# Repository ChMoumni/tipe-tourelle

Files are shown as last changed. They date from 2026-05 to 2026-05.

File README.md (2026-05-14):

# TIPE – Tourelle de visée motorisée

<p align="center">
  Système complet
</p>

Conception et réalisation d'une tourelle motorisée pilotée par joystick, avec suivi automatique d'objet par caméra Pixy2 et système de tir électromagnétique (coilgun).  
Projet mené dans le cadre de mon TIPE (2025-2026).

## 🎯 Objectif du projet

Développer un système de visée motorisé capable de :
- Être piloté manuellement via un joystick
- Suivre automatiquement un objet coloré en temps réel
- Déclencher un tir électromagnétique sur cible
- Servir de plateforme d'étude pour l'asservissement et la cinématique

## 🛠️ Technologies utilisées

- **Microcontrôleur** : Arduino Uno
- **Langage** : C++ embarqué
- **Capteur** : Pixy2 CMUcam (reconnaissance couleur)
- **Actionneurs** : 2 servomoteurs FS5323M
- **Entrée** : Joystick analogique 2 axes
- **Simulation** : Wokwi
- **CAO** : FreeCAD & Autodesk Fusion 360

## 🎮 Fonctionnalités

### Mode Manuel
- Pilotage horizontal/vertical par joystick
- Zone morte configurable
- Vitesse progressive

### Mode Automatique
- Détection d'objets colorés
- Asservissement PD (Kp = 0,15, Kd = 0,05)
- Commutation manuel/auto par série

### Commandes série
- `a` : Mode automatique
- `m` : Mode manuel  
- `c` : Centrer la tourelle

## 🔫 Système de tir (Coilgun)

La tourelle intègre un canon électromagnétique (coilgun) en tête de système.

### Principe de fonctionnement
- Un banc de condensateurs (30 mF, 60 V) stocke l'énergie
- La décharge dans une bobine crée un champ magnétique puissant
- Une bille en acier (Ø 5 mm) est propulsée par effet magnétique

### Circuit électrique

| Composant | Valeur | Rôle |
|---|---|---|
| Condensateur | 30 mF (3 × 10 000 μF / 63 V) | Stockage d'énergie |
| Bobine | L = 1,4 mH, rL = 3 Ω | Inducteur |
| Résistance série | 0,1 Ω | Limitation du courant |
| Résistance de charge | 100 Ω | Charge du condensateur |
| MOSFET | IRFB4227 | Interrupteur de puissance |
| Diode | 1N5408 | Protection flyback |
| Résistance de grille | 470 Ω | Pilotage MOSFET |

### Performances actuelles
- Énergie stockée : **54 J**
- Énergie transmise au projectile : ≈ **0,5 J** (rendement ≈ 1%)
- Portée : plusieurs mètres

### Améliorations envisagées
- [ ] Dimensionnement optimal de la bobine (calculs en cours)
- [ ] Remplacer le MOSFET par un IGBT (IGW60T120) pour supporter des courants plus élevés
- [ ] Commande du tir depuis l'Arduino (automatisation)
- [ ] Réduction de la résistance interne de la bobine pour améliorer le rendement

> Voir section 7 du rapport pour les détails de conception et les essais.

## 🔗 Simulation du mode manuel (Wokwi)

[→ Simuler la commande joystick → servomoteurs](https://wokwi.com/projects/456061970656974849)

*Version préliminaire ayant servi de base au mode manuel actuel (sans zone morte ni gestion de vitesse). Le code final de la tourelle complète est disponible dans [`code/tipe_tourelle_visee.ino`](code/tipe_tourelle_visee.ino).*

## 🔧 Installation

1. Cloner le dépôt
2. Câbler selon schéma (servos pins 9/10, joystick A0/A1)
3. Téléverser le code Arduino
4. Ouvrir le moniteur série (115200 bauds)

## 📊 Résultats

<p align="center">
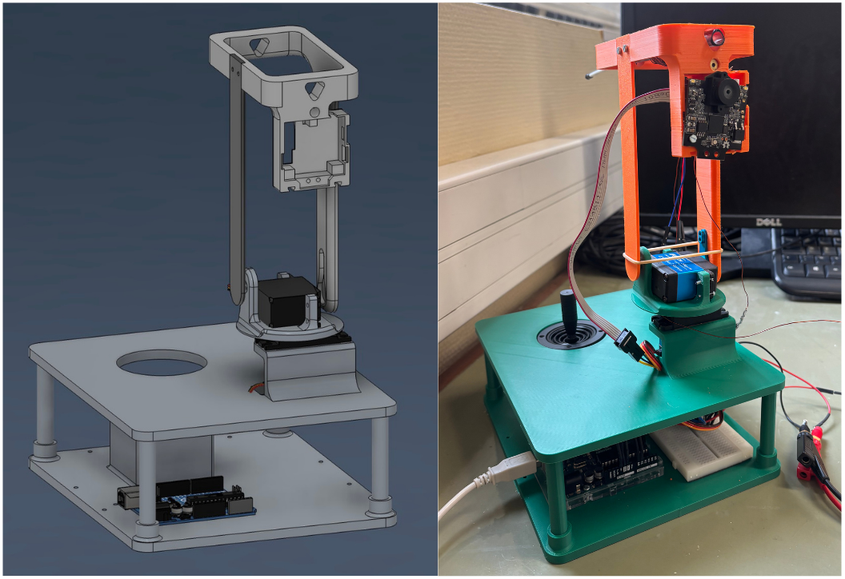
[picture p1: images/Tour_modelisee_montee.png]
Comparaison CAO / Réel
  
</p>

## 🧩 État d'avancement

### Mécanique
- [x] Modélisation 3D complète (6 pièces) [`cad/`](cad/) (visualisables directement sur GitHub)
- [x] Impression 3D
- [x] Assemblage final

### Électronique & Code
- [x] Simulation Wokwi (version préliminaire)
- [x] Câblage et tests
- [x] Code fonctionnel (manuel + auto)
- [x] Circuit coilgun opérationnel

### Système de tir
- [x] Banc de condensateurs 30 mF / 60 V
- [x] Bobine artisanale fonctionnelle
- [ ] Dimensionnement optimal de la bobine (calculs en cours)
- [ ] Amélioration du rendement énergétique

### Documentation
- [x] README
- [x] Description des pièces
- [ ] Rapport final (en cours - rédaction LaTeX)
- [ ] Schéma cinématique (graphe des liaisons)

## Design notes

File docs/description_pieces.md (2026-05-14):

# Description des pièces mécaniques

Ce document décrit le rôle de chaque pièce modélisée sur FreeCAD et Fusion 360.  
Une version définitive (schéma cinématique, graphe de liaisons) sera rédigée dans le rapport final.

**📁 Les fichiers CAO (`.stl` et `.step`) sont disponibles dans le dossier [`../cad/`](../cad/) et visualisables directement sur GitHub.**

---

## Vue d'ensemble des 6 pièces

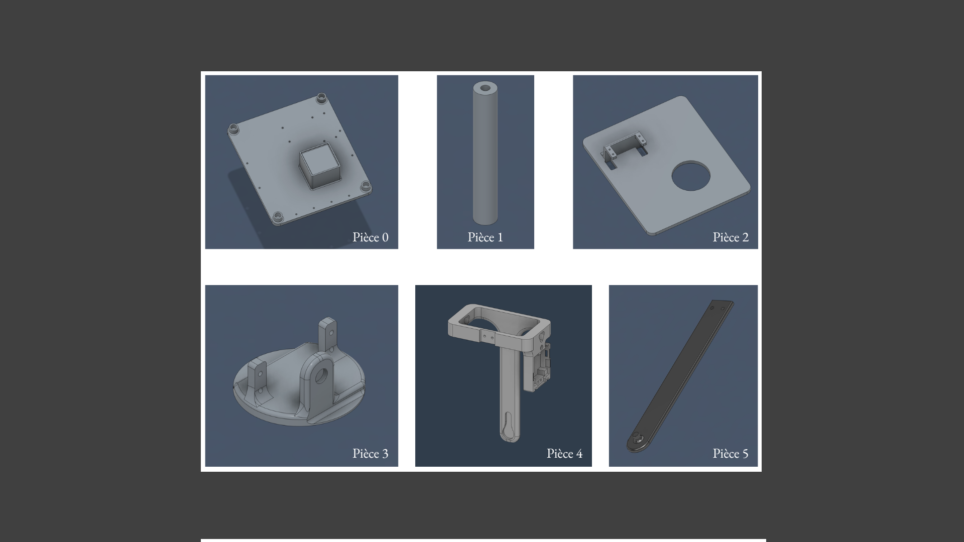
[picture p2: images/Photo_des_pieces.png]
Ensemble des 6 pièces


---

## Détail des pièces

| Pièce | Nom | Vue | Rôle |
|---|-----|-----|---|
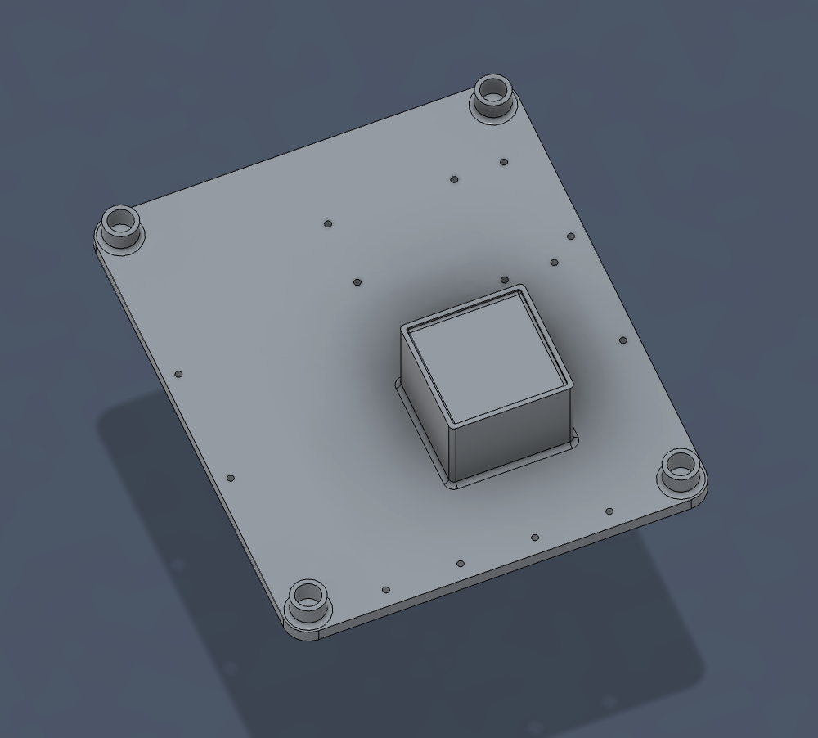
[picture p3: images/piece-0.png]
| **0** | Bâti (base fixe) |  | Base fixe de la tourelle. Accueille le breadboard, Arduino et joystick. Quatre logements cylindriques reçoivent les colonnes. |
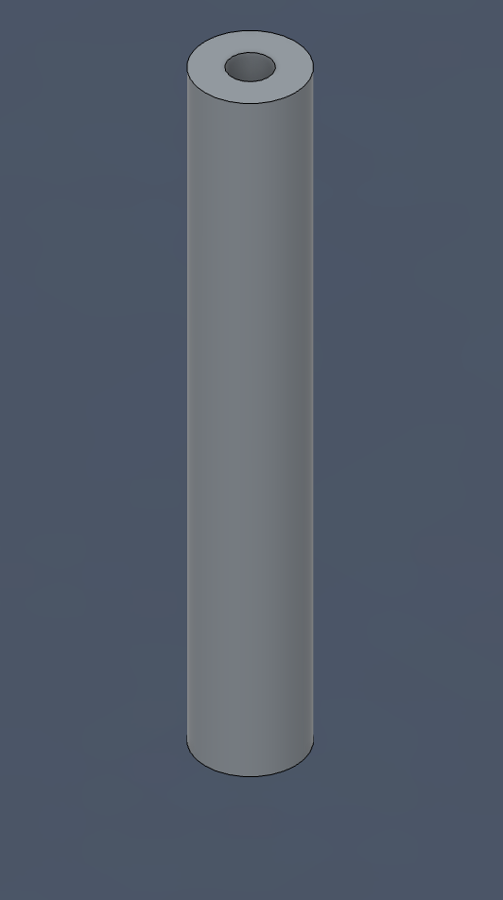
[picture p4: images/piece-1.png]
| **1** | Colonne (×4) |  | Colonne cylindrique creuse imprimée en 4 exemplaires. Sert de support entre la pièce 0 et la pièce 2. |
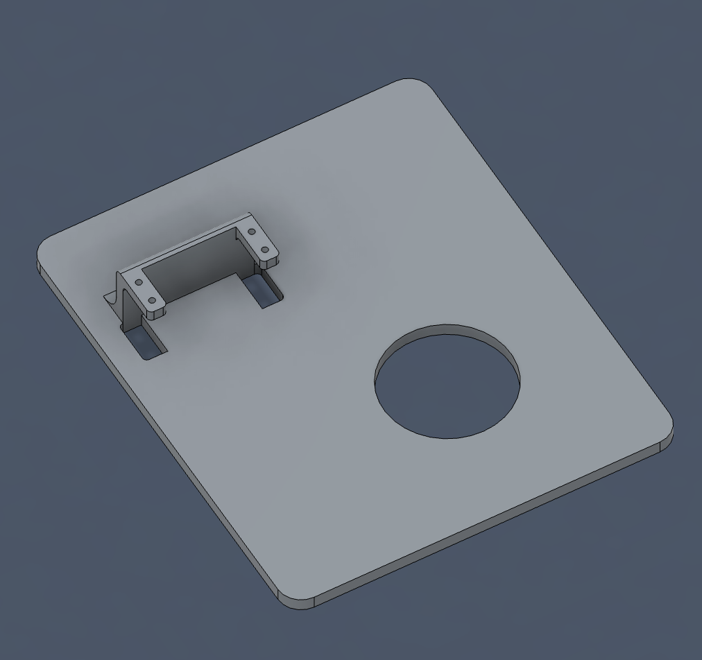
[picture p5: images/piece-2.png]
| **2** | Plateau intermédiaire |  | Porte le servomoteur horizontal. S'emboîte sur les colonnes. Protège les composants électroniques. |
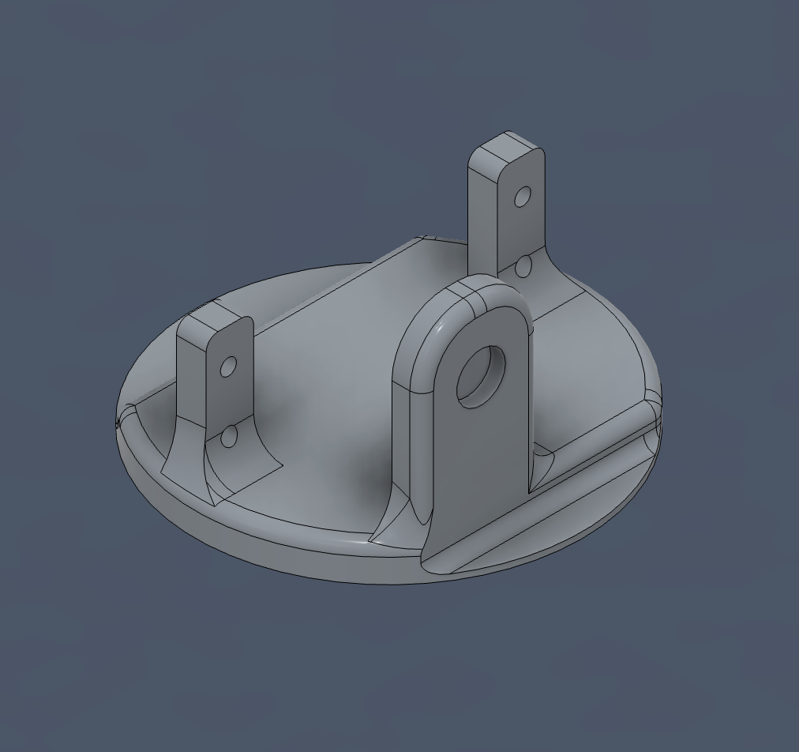
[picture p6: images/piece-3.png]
| **3** | Bras tournant |  | Encastré sur l'arbre du servo horizontal. Porte le servomoteur vertical. Logement pour roulement à billes. |
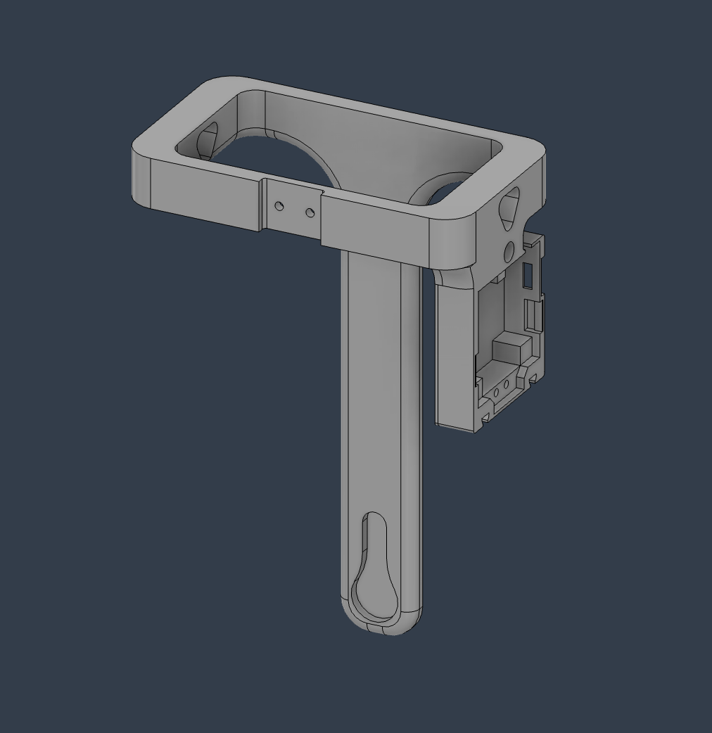
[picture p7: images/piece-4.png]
| **4** | Tête |  | Porte la caméra Pixy2, le laser et le **coilgun** (canon électromagnétique). Fixée sur le servo vertical. |
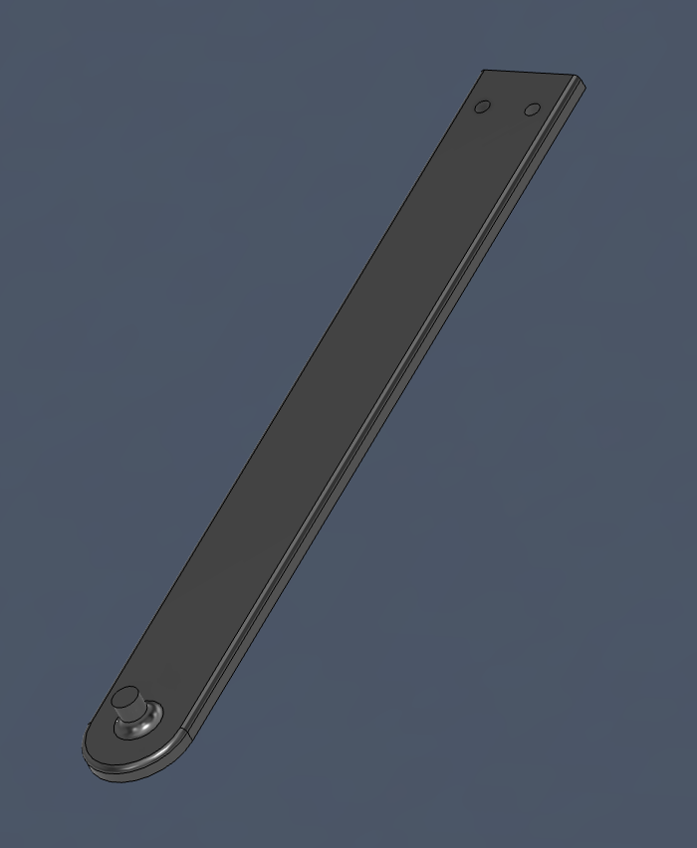
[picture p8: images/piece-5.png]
| **5** | Jonction |  | Vissée sur la pièce 4. Son cylindre se loge dans le roulement de la pièce 3, réalisant la liaison pivot. |

---

## Récapitulatif

| Pièce | Nom | Qté | Mouvement | Actionneur |
|---|-----|-----|---|---|
| 0 | Bâti | 1 | Fixe | - |
| 1 | Colonne | 4 | Fixe | - |
| 2 | Plateau intermédiaire | 1 | Fixe | - |
| 3 | Bras tournant | 1 | Rotation horizontale (pan) | Servo H |
| 4 | Tête | 1 | Rotation verticale (tilt) | Servo V |
| 5 | Jonction | 1 | Fixe (liaison pivot 3-4) | - |

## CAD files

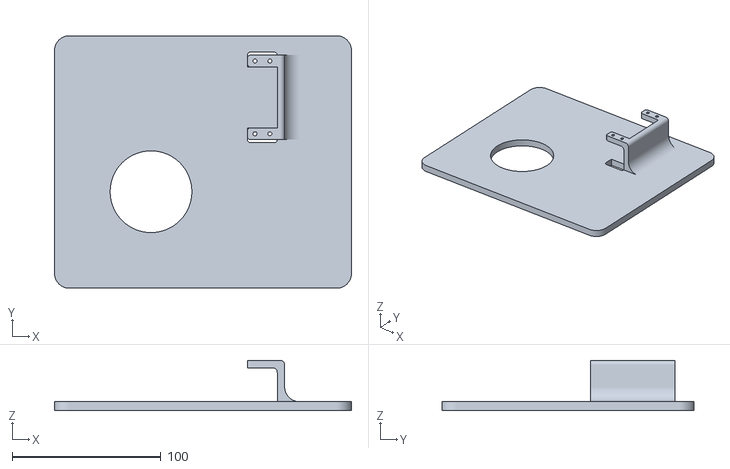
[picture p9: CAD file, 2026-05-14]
cad/piece-2.stl
200.0 x 170.0 x 33.8

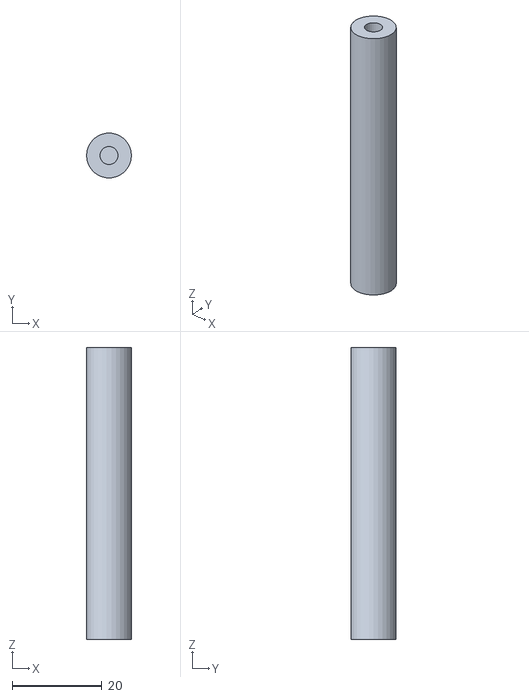
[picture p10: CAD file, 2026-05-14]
cad/piece-1.stl
10.0 x 9.95 x 65.0

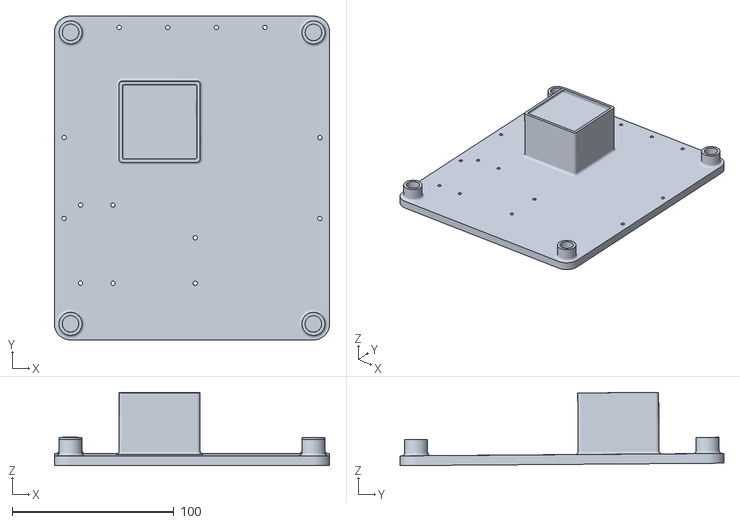
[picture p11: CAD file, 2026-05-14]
cad/piece-0.stl
170.1 x 200.1 x 45.3

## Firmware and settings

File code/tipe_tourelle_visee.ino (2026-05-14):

#include <Servo.h>
#include <Pixy2.h>

// === Déclarations des objets ===
Servo servo_horizontal;
Servo servo_vertical;
Pixy2 pixy;

// === Variables de contrôle ===
bool modeAuto = false;
float angleHorizontal = 90;
float angleVertical = 90;
float oldAngleHorizontal = 90;
float oldAngleVertical = 90;

// === Paramètres du joystick ===
const int pinJoystickX = A0;
const int pinJoystickY = A1;
const int zoneMorte = 60;

// === Paramètres de vitesse ===
const float vitesseH = 1.2;
const float vitesseV = 1.2;

// === Paramètres du PID ===
float erreurPrecedenteX = 0;
float erreurPrecedenteY = 0;

unsigned long dernierAffichage = 0;

void setup() {
  Serial.begin(115200);
  Serial.println("=== Systeme de visee motorisee ===");
  Serial.println("Mode Manuel par defaut. Utilisez le joystick.");
  Serial.println("Tapez 'a' pour mode Auto (suivi d'objet)");
  Serial.println("Tapez 'm' pour revenir en mode Manuel");
  Serial.println("Tapez 'c' pour centrer la tourelle");
  Serial.println("--------------------------------------");
  
  servo_horizontal.attach(9);
  servo_vertical.attach(10);
  
  servo_horizontal.write(angleHorizontal);
  servo_vertical.write(angleVertical);

  // === Laser (broche 8) ===
  pinMode(8, OUTPUT);
  digitalWrite(8, HIGH);  // Allumé au démarrage
  
  pixy.init();
  delay(100);
}

void loop() {
  // === Changement de mode ===
  if (Serial.available()) {
    char commande = Serial.read();
    if (commande == 'a' || commande == 'A') {
      modeAuto = true;
      Serial.println(">>> Mode AUTOMATIQUE active <<<");
    } else if (commande == 'm' || commande == 'M') {
      modeAuto = false;
      Serial.println(">>> Mode MANUEL active <<<");
    } else if (commande == 'c' || commande == 'C') {
      angleHorizontal = 90;
      angleVertical = 90;
      servo_horizontal.write(90);
      servo_vertical.write(90);
      Serial.println(">>> Centrage effectue <<<");
    }
  }
  
  if (modeAuto) {
    // ==================== MODE AUTOMATIQUE ====================
    pixy.ccc.getBlocks();
    
    if (pixy.ccc.numBlocks > 0) {
      int x = pixy.ccc.blocks[0].m_x;
      int y = pixy.ccc.blocks[0].m_y;
      
      int erreurX = x - 158;  // Centre de l'image Pixy (316/2)
      int erreurY = y - 104;  // Hauteur Pixy (208/2)
      
      float correctionX = erreurX * 0.015 + (erreurX - erreurPrecedenteX) * 0.05;
      float correctionY = erreurY * 0.015 + (erreurY - erreurPrecedenteY) * 0.05;
      
      erreurPrecedenteX = erreurX;
      erreurPrecedenteY = erreurY;

      oldAngleHorizontal = angleHorizontal;
      oldAngleVertical = angleVertical;
      
      angleHorizontal = constrain(angleHorizontal - correctionX, 10, 170);
      angleVertical = constrain(angleVertical + correctionY, 10, 170);
      
      // Filtrer les mouvements trop brusques
      if (abs(angleHorizontal - oldAngleHorizontal) < 15 && abs(angleVertical - oldAngleVertical) < 15) {
          servo_horizontal.write(angleHorizontal);
          servo_vertical.write(angleVertical);
      }
      
      unsigned long maintenant = millis();
      if (maintenant - dernierAffichage > 300) {
        Serial.print("AUTO - Objet: X=");
        Serial.print(x);
        Serial.print(" Y=");
        Serial.print(y);
        Serial.print(" | Servos: H=");
        Serial.print(angleHorizontal);
        Serial.print("° V=");
        Serial.println(angleVertical);
        dernierAffichage = maintenant;
      }
    } else {
      unsigned long maintenant = millis();
      if (maintenant - dernierAffichage > 1000) {
        Serial.println("AUTO - Aucun objet detecte");
        dernierAffichage = maintenant;
      }
    }

  } else {
    // ==================== MODE MANUEL ====================
    
    int valeurX = analogRead(pinJoystickX);
    int valeurY = analogRead(pinJoystickY);
    
    // Application de la zone morte
    int deltaX_brut = (abs(valeurX - 512) < zoneMorte) ? 0 : (valeurX - 512);
    int deltaY_brut = (abs(valeurY - 512) < zoneMorte) ? 0 : (valeurY - 512);
    
    float deltaX = deltaX_brut / 512.0;
    float deltaY = deltaY_brut / 512.0;
    
    angleHorizontal = constrain(angleHorizontal + deltaX * vitesseH, 10, 170);
    angleVertical   = constrain(angleVertical - deltaY * vitesseV, 10, 170);
    
    servo_horizontal.write(angleHorizontal);
    servo_vertical.write(angleVertical);
    
    unsigned long maintenant = millis();
    if (maintenant - dernierAffichage > 300) {
      Serial.print("MANUEL - Joystick: X=");
      Serial.print(valeurX);
      Serial.print(" Y=");
      Serial.print(valeurY);
      Serial.print(" | Servos: H=");
      Serial.print(angleHorizontal);
      Serial.print("° V=");
      Serial.println(angleVertical);
      dernierAffichage = maintenant;
    }
  }
  
  delay(20);
}
